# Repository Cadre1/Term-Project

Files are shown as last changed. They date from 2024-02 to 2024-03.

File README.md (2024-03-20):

# Term Project
 Group 18's Term Project
 
 Christopher Ng, Dylan Featherson, Edward Eyre

# Introduction
This project introduces an autonomous turret system designed to display enhanced target acquisition and firing capabilities for Nerf or similar projectile launchers. The primary purpose of this device is to autonomously locate the centroid of heat in a designated area through a thermal camera and adjust the yaw of the Nerf gun to aim precisely at the detected target. While the pitch remains fixed, our turret system ensures accurate horizontal alignment for firing at the identified heat source. The device is primarily intended for recreational use, targeting enthusiasts of Nerf or similar foam projectile launchers who seek an enhanced and automated shooting experience. Additionally, our turret system can be of interest to hobbyists, makers, and engineering students interested in exploring mechatronics, automation, and robotics applications. With its autonomous targeting capabilities, the device offers a unique and engaging way to enjoy Nerf battles while showcasing advancements in technology integration and automation.

# Final Product




The Project in Action - https://youtu.be/ceA77QBQG_Y?si=SO-bap_1HtrvdEz_

# Hardware Design
Using the CAD model shown here and parts provided in the CAD folder, we developed laser printed wood parts for the main structural design of the turret along with specific 3D printed parts for components such as electronic fixtures, gears, and other small parts with sizings measured for the actual products. 



# Electronic Schematic
Using the electronic schematic shown here, we wired the STM32 Nucleo to its corresponding electronic components with extended wires and external power sources.



# Software Design
Using the finite state machines shown here, we programmed our system accordingly to produce our controlled results. 

The program documentation can be found here - https://cadre1.github.io/Term-Project/




# Results
Our system underwent rigorous testing on the designated battle table, which spanned 8 feet in length. During these tests, we evaluated its performance in various scenarios by setting up targets at different positions, heat levels, and time settings. Provided enough testing for general settings, the system demonstrated accurate target acquisition and aiming, proving its reliability under simulated battle conditions. With proper calibration of the IR sensor and a functional Nerf gun, the turret successfully located and fired at targets with precision, showcasing its effectiveness in autonomous operation.

# Challenges and Lessons Learned
Despite its overall success, we encountered challenges primarily related to mechanical components, particularly the undersized 3D printed spur gear teeth, and some detection of hotspots. Issues with too shallow of gear teeth depth and wear due to material choice and sizing resulted in occasional slipping and improper meshing of gears, necessitating slow and careful adjustments to ensure smooth turret rotation. This mainly showed to our lack in experience in developing gears for situations under medium amounts of play between moving parts. Provided more time, this issue could have been remedied by recutting wood and moving the motor location to better contact the annular gear, increasing gear teeth sizes, and/or altering our gear type to be spur gears to be able to mesh the two and have more room for error. In addition, maintaining proper calibration of the IR sensor and addressing potential jams in the Nerf gun were critical for optimal performance. Further adjustments for higher mounting of the thermal camera or a more sophisticated algorithim for horizontal hotspot calculation could have helped in aiming. From these challenges, we learned the importance of meticulous component sizing and compatibility checks, as well as the significance of thorough calibration procedures for sensor-based systems.



# Recomendations
For those seeking to build upon our work, we recommend prioritizing careful sizing and compatibility checks of mechanical components to prevent issues such as gear slipping. Additionally, implementing regular maintenance checks and calibration procedures for sensors and actuators is essential for consistent performance. Exploring alternative materials or manufacturing methods for gears could improve durability and reliability. Furthermore, integrating additional sensors or advanced algorithms for target tracking could enhance the system's accuracy and adaptability in dynamic environments. Overall, these recommendations aim to address challenges encountered during our project and offer avenues for further refinement and improvement in future iterations.

# References
Inspiration for the project: 

Vinnie San’s automatic turret - https://www.youtube.com/watch?v=dkEc3wjEfYc

<br>

Hardware and software manuals and support documents:

Helpful Code for ME 405 - https://github.com/spluttflob/ME405-Support

STM32L476 Nucleo User Manual - https://www.st.com/resource/en/user_manual/um1724-stm32-nucleo64-boards-mb1136-stmicroelectronics.pdf

MLX90640 Thermal Camera Datasheet - https://www.melexis.com/en/documents/documentation/datasheets/datasheet-mlx90640

HEXFLY 25kg Metal Gear Servo Specifications - https://www.redcatracing.com/products/rer11856?variant=30993858625626

IRLB8721PbF MOSFET Datasheet - https://www.infineon.com/dgdl/irlb8721pbf.pdf?fileId=5546d462533600a40153566056732591

L7805CV Voltage Regulator Datasheet - https://www.mouser.com/datasheet/2/389/l78-1849632.pdf

Nerf Gun - https://www.amazon.com/NERF-Motorized-Blaster-6-Dart-Compatible/dp/B08HSRQ1QV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

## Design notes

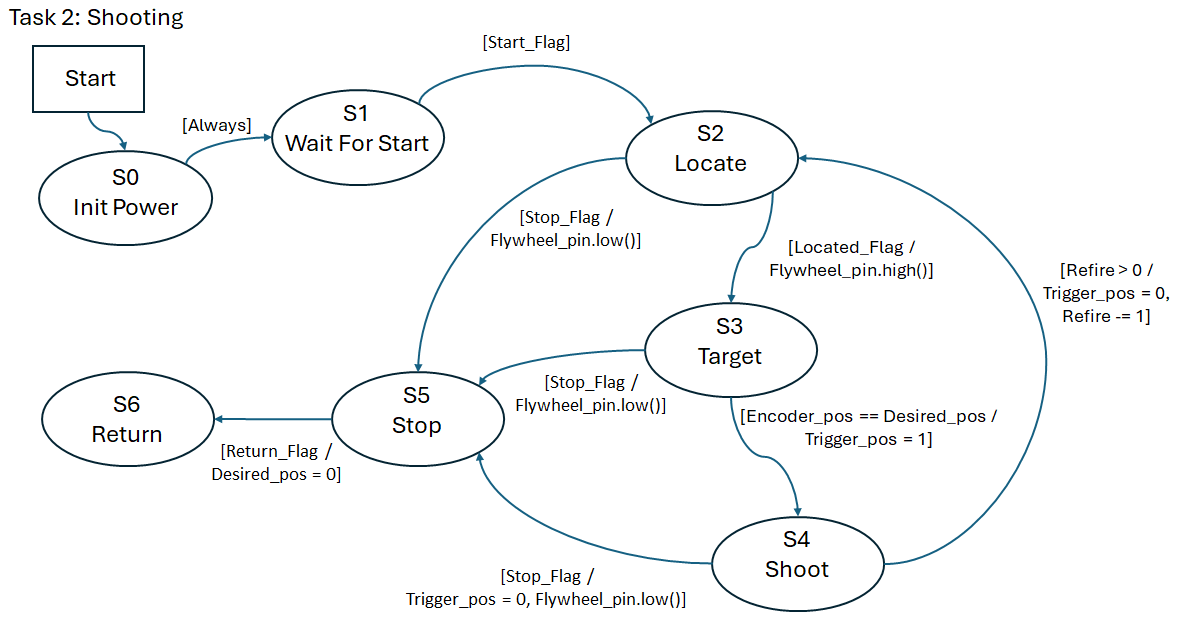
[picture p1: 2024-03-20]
docs/Task2_FSM.png

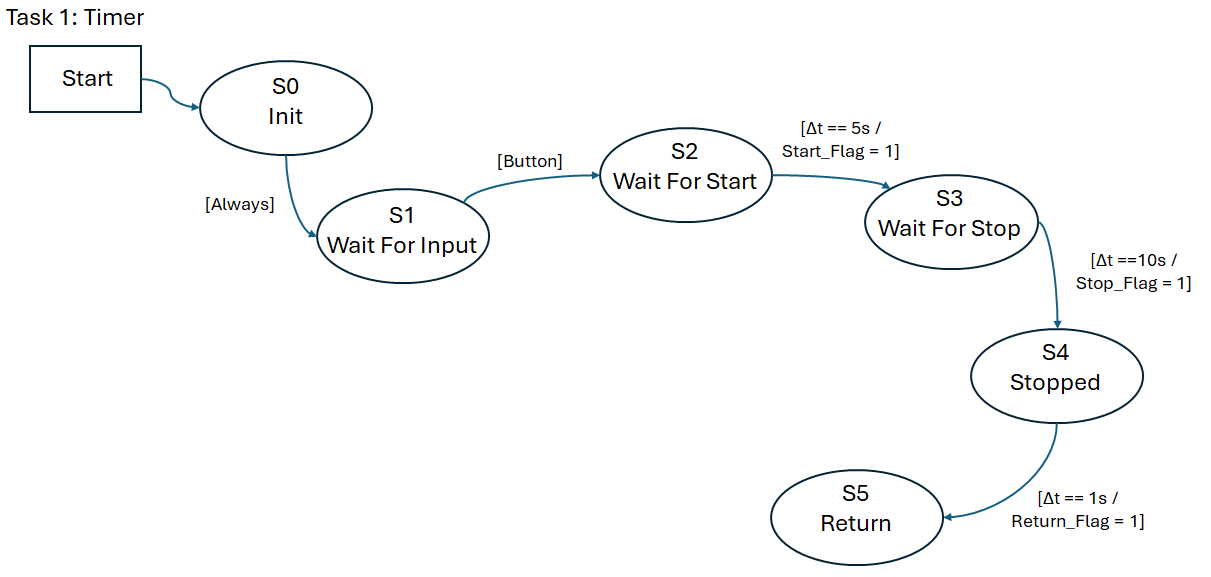
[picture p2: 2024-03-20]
docs/Task1_FSM.png

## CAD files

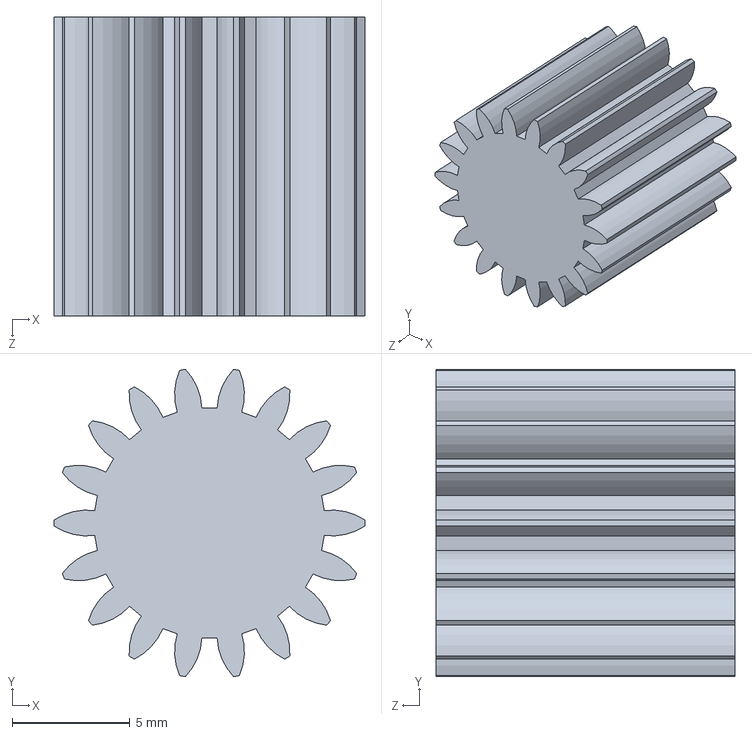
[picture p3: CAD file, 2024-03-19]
CAD/3D Print Parts/Pinion_Gear.SLDPRT
13.2 x 13.1 x 12.7 mm

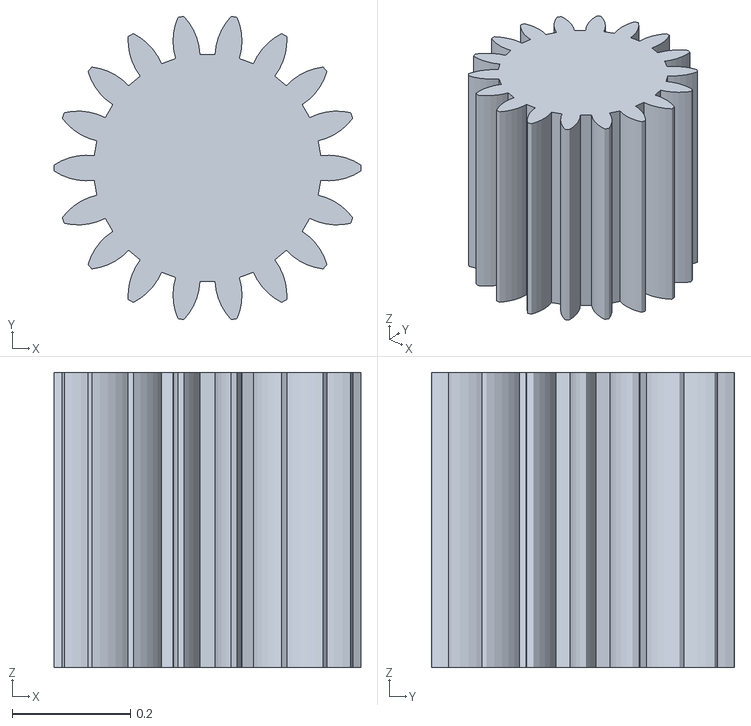
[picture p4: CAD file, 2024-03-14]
CAD/Pinion_GearV3_Large_Teeth.STL
0.52 x 0.514 x 0.5

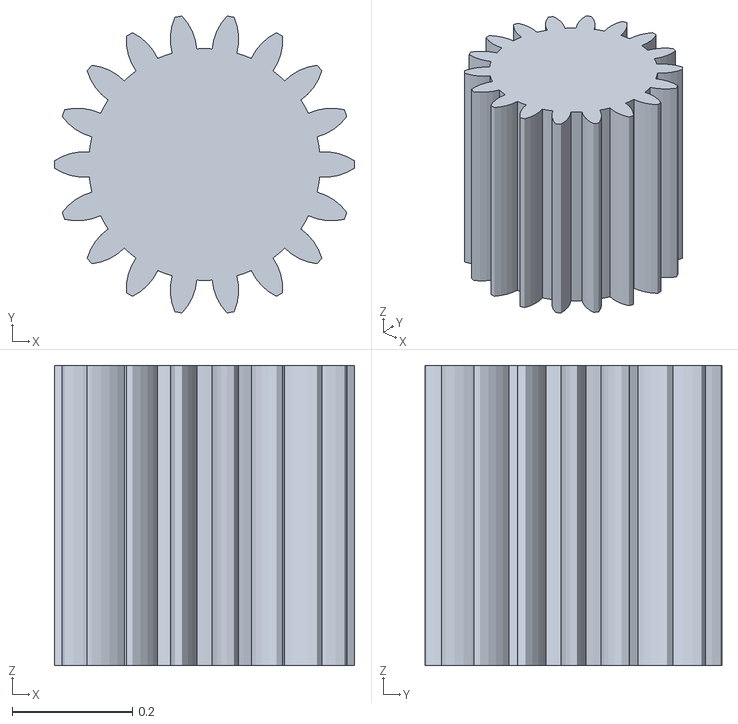
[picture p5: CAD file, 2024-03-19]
CAD/3D Print Parts/Pinion_GearV3.STL
0.5 x 0.494 x 0.5

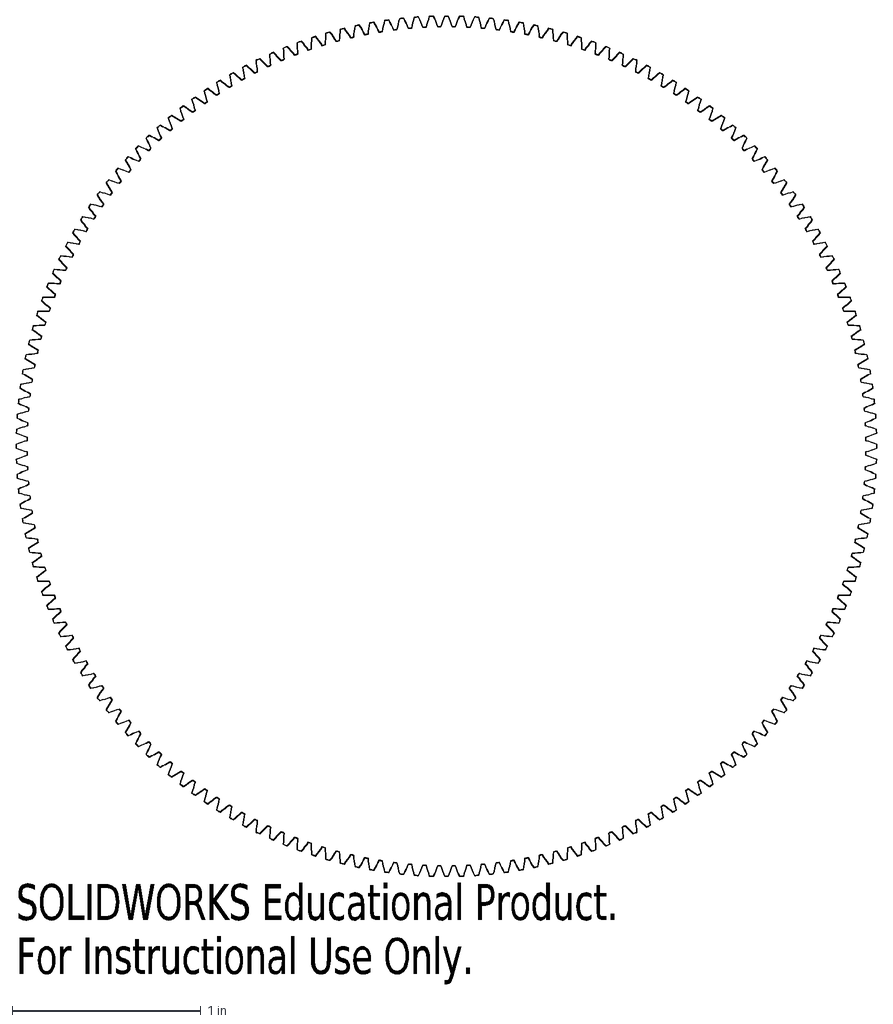
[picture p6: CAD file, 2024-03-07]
CAD/internal spur gear_ai_modified.DXF
SOLIDWORKS Educational Product.
For Instructional Use Only.

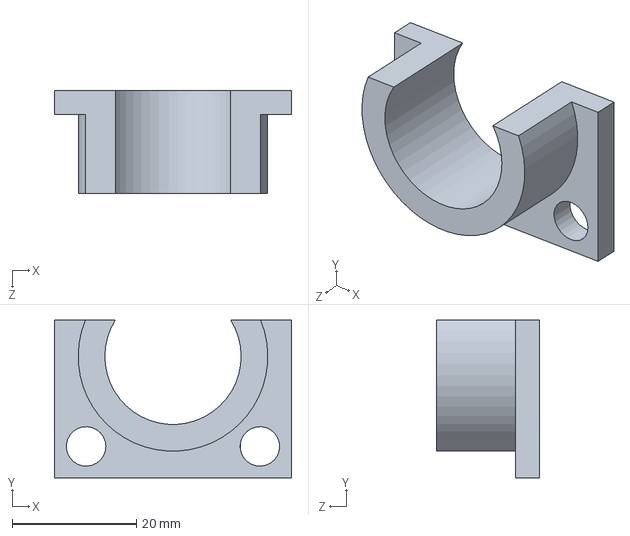
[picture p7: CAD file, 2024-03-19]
CAD/3D Print Parts/Vertical_Motor_Holder.SLDPRT
38.1 x 25.4 x 16.5 mm

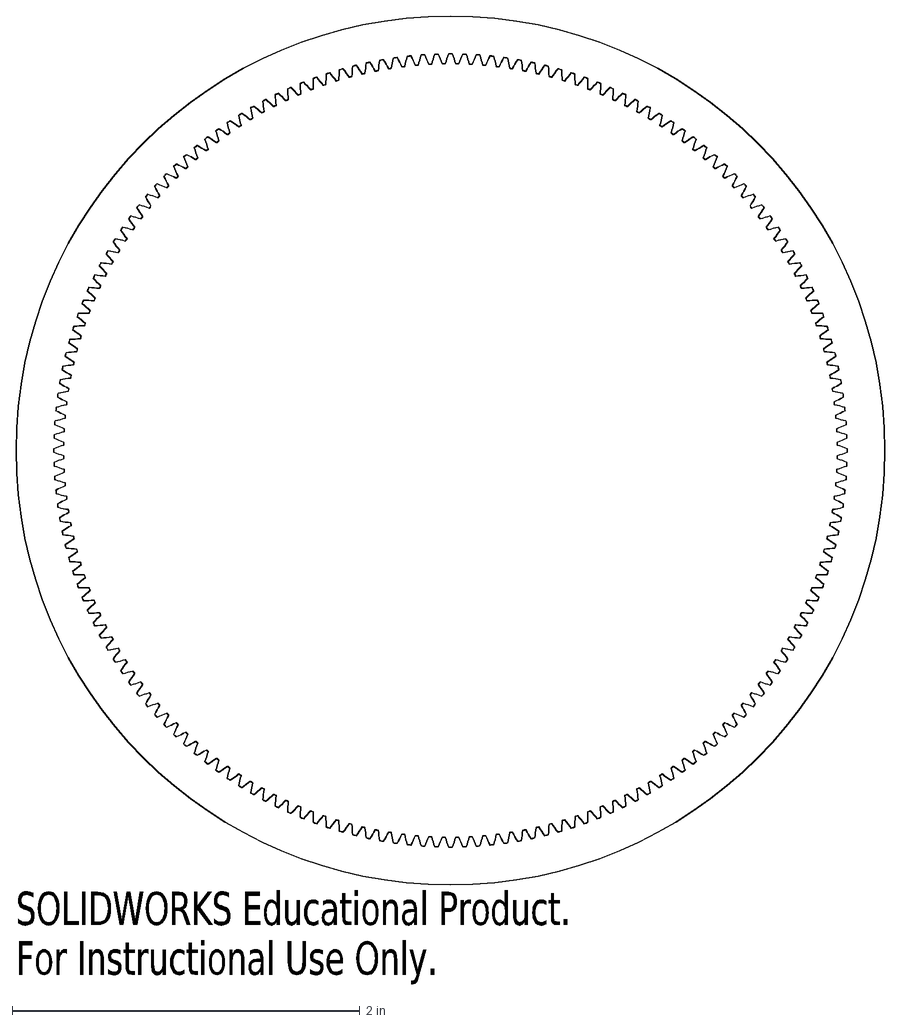
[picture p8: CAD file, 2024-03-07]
CAD/internal spur gear_ai.DXF
SOLIDWORKS Educational Product.
For Instructional Use Only.

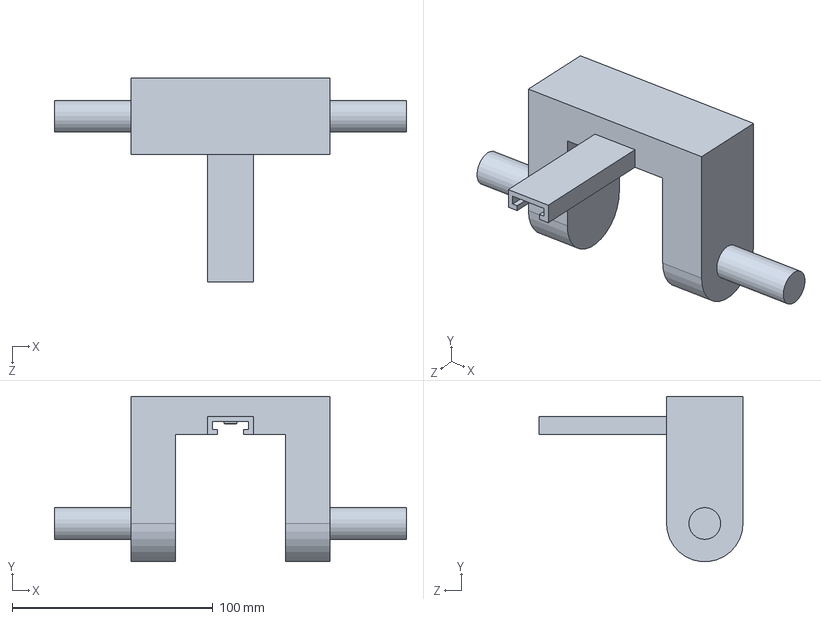
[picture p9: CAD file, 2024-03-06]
CAD/3D Print Parts/Nerf_Gun_Rail_Attachment.SLDPRT
175.3 x 82.2 x 101.6 mm

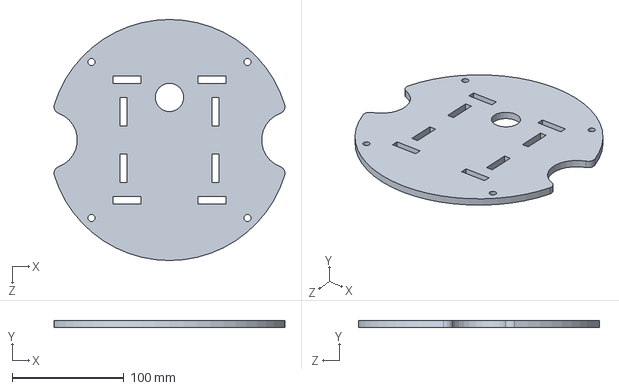
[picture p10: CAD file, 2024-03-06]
CAD/Base.SLDPRT
206.9 x 6.35 x 215.9 mm

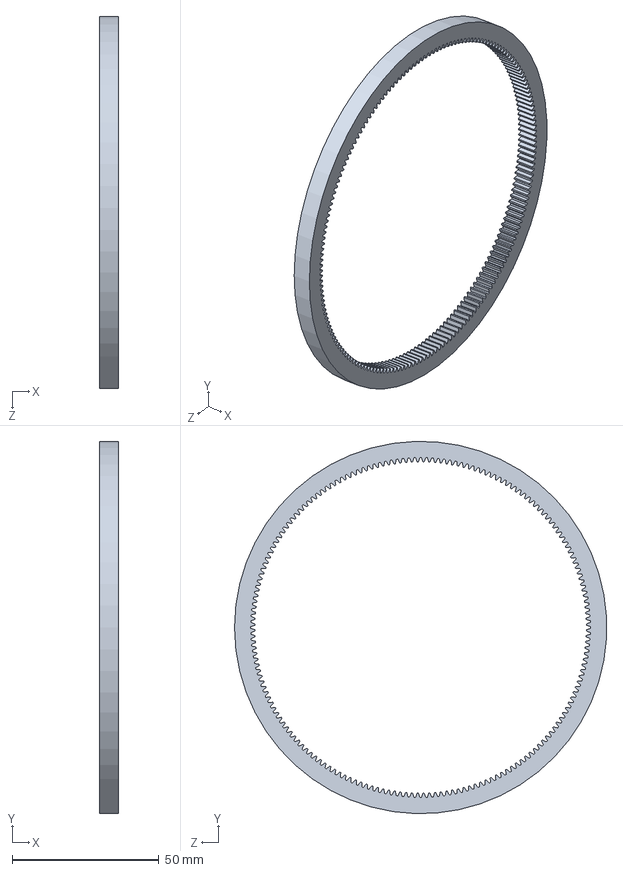
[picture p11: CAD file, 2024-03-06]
CAD/3D Print Parts/Annular_Gear.SLDPRT
6.35 x 126.9 x 126.9 mm

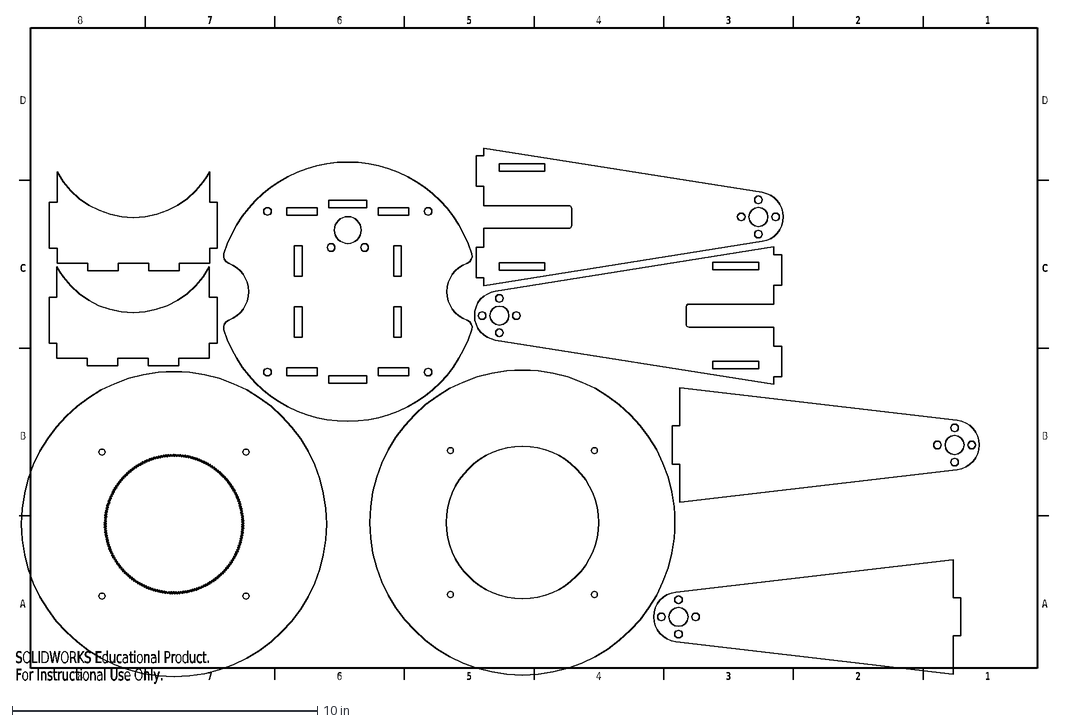
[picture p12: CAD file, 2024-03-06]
CAD/Laser_Cut.DXF
A
B
C
D
8
7
6
5
4
3
2
1
SOLIDWORKS Educational Product.
For Instructional Use Only.

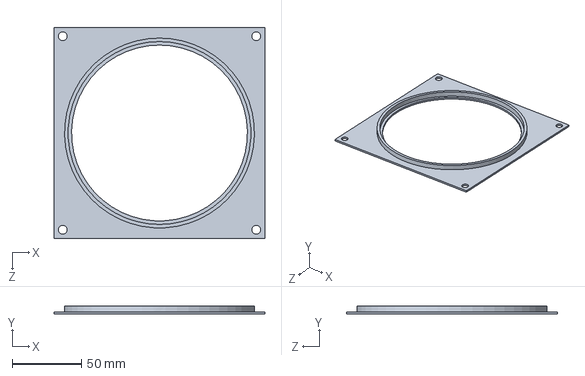
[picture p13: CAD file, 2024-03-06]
CAD/Lazy Susan Bottom Rotatable.SLDPRT
152.4 x 6.03 x 152.4 mm

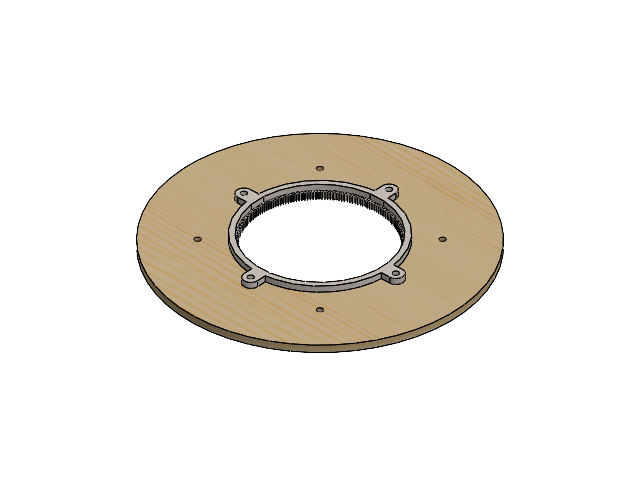
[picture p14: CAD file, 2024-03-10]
CAD/Base_Plate.SLDASM
internal spur gear_ai
Table Support Rotatable

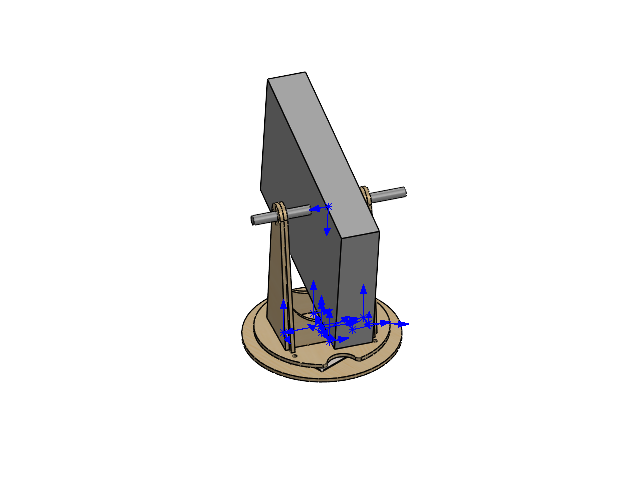
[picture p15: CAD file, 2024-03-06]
CAD/Assembly.SLDASM
Base
Supports x 2
Lazy Susan
Lazy Susan Bottom Rotatable
Truss x 2
Truss Support x 2
Nerf Gun and Axle
Motor Stand-In
internal spur gear_ai
Table Support Rotatable
Pinion_Gear
Vertical_Motor_Holder

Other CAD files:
CAD/3D Print Parts/Pinion_Gear_More_Fill.SLDPRT
CAD/Truss Support.SLDPRT
CAD/Motor Stand-In.SLDPRT
CAD/Supports.SLDPRT
CAD/Table Support Rotatable.SLDPRT
CAD/3D Print Parts/Annular_Gear.STL
CAD/3D Print Parts/Nerf_Gun_Rail_Attachment.STL
CAD/3D Print Parts/Pinion_Gear.STL
CAD/3D Print Parts/Pinion_GearV2.STL
CAD/3D Print Parts/Pinion_Gear_More_Fill.STL
CAD/3D Print Parts/Vertical_Motor_Holder.STL
CAD/Assembly.SLDDRW
CAD/Base Gear.SLDPRT
CAD/Base.DXF
CAD/Bearing Restraint.SLDPRT
CAD/Bearing Stand In.SLDPRT
CAD/Bottom Gear.SLDPRT
CAD/Laser_Cut.DWG
CAD/Laser_Cut.SLDDRW
CAD/Lazy Susan.SLDPRT
CAD/Motor Pulley.SLDPRT
CAD/Nerf Gun and Axle.SLDPRT
CAD/Pinion_GearV2_Large_Teeth.STL
CAD/Shaft Pulley.SLDPRT
CAD/Supports.DXF
CAD/Table Support Rotatable.DXF
CAD/Truss Support.DXF
CAD/Truss.DXF
CAD/Truss.SLDPRT

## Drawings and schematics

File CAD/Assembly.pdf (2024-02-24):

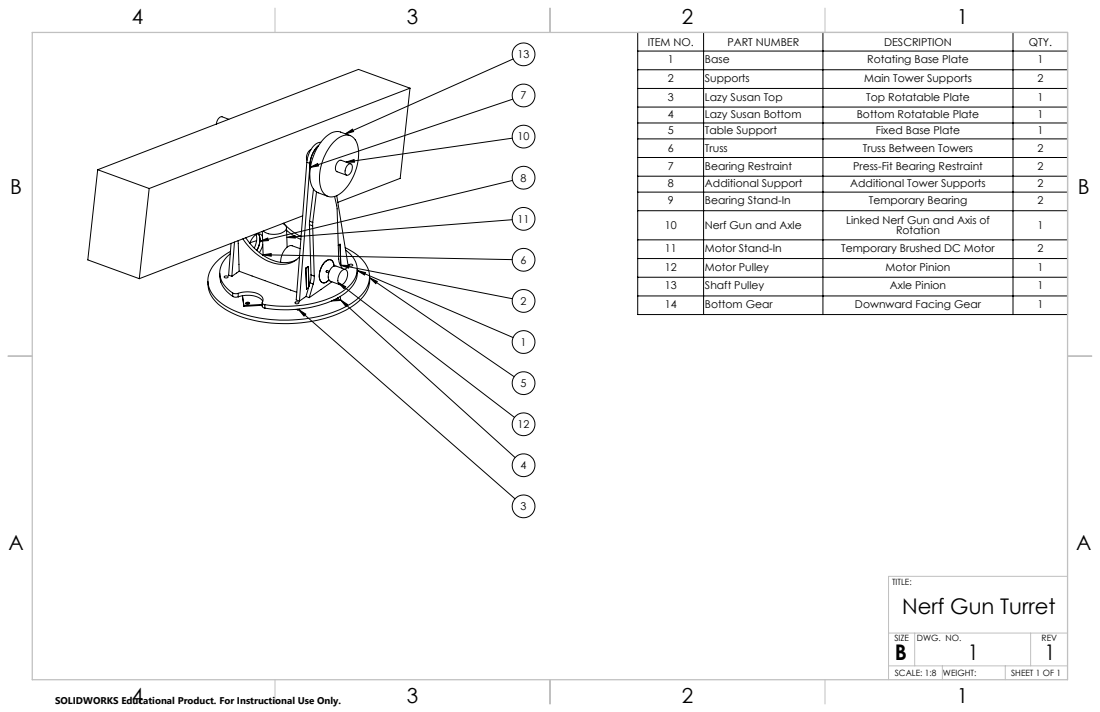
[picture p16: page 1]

ITEM NO. | PART NUMBER | DESCRIPTION | QTY.
1 | Base | Rotating Base Plate | 1
2 | Supports | Main Tower Supports | 2
3 | Lazy Susan Top | Top Rotatable Plate | 1
4 | Lazy Susan Bottom | Bottom Rotatable Plate | 1
5 | Table Support | Fixed Base Plate | 1
6 | Truss | Truss Between Towers | 2
7 | Bearing Restraint | Press-Fit Bearing Restraint | 2
8 | Additional Support | Additional Tower Supports | 2
9 | Bearing Stand-In | Temporary Bearing | 2
10 | Nerf Gun and Axle | Linked Nerf Gun and Axis of Rotation | 1
11 | Motor Stand-In | Temporary Brushed DC Motor | 2
12 | Motor Pulley | Motor Pinion | 1
13 | Shaft Pulley | Axle Pinion | 1
14 | Bottom Gear | Downward Facing Gear | 1

TITLE:
Nerf Gun Turret

SIZE B | DWG. NO. 1 | REV 1

SCALE: 1:8 | WEIGHT: | SHEET 1 OF 1

SOLIDWORKS Educational Product. For Instructional Use Only.

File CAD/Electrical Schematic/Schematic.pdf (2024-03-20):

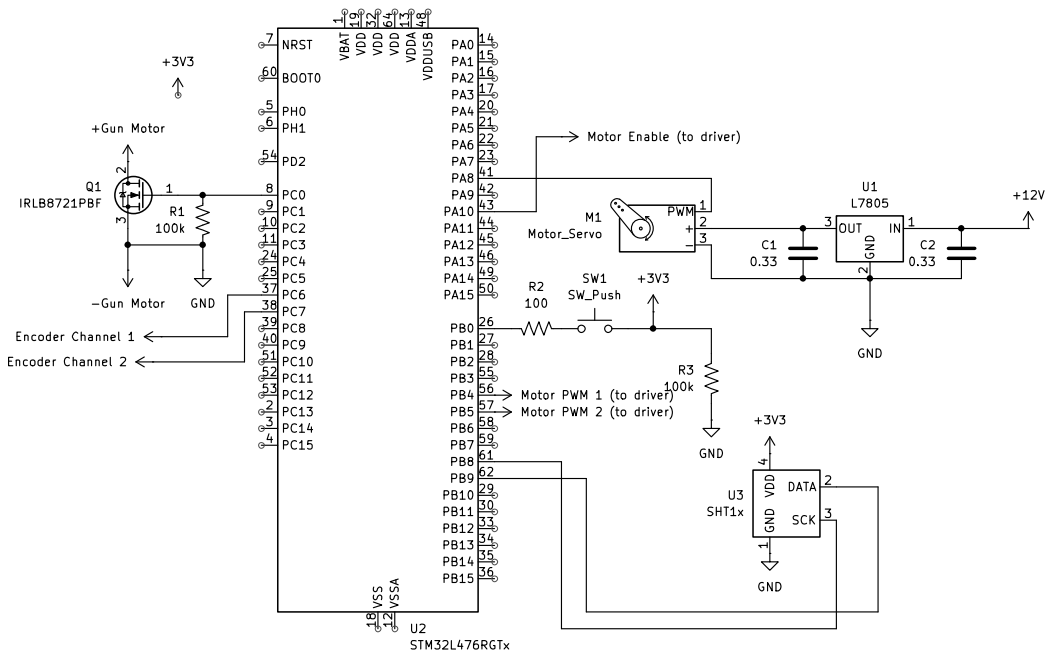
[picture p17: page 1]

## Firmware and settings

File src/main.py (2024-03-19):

"""!
@file main.py
    This program manages and allows two cotasks, task1_fun (Timing) and task2_fun (Shooting), to be run without blocking each other upon the microcontroller's reset.
    The Timing task initializes a pin to take an input from a button in which it then begins to track each of the required timers for the shootout.
    Each section of the shootout will have its corresponding flag set when each timer ends.
    The Shooting task initializes the pin controlling the MOSFET output to the Nerf gun flywheel, the I2C channel for the thermal camera, the pins and timers for the panning motor and encoder, and the pin, timer, and PID controller for the servo motor.
    This task will then manage the motor control for initial rotation using the motor driver, encoder, and PID controller, the centroid/hotspot detection using the thermal camera, the aiming at the determined centroid/hotspot, firing using the pin-to-flywheel circuit and servo motor, and rotation back to its starting point.
    During each of the shootout's sections, the states will be watching for changes in the timer's flag changes and change modes correspondingly. 
    Notes:
    * Each of these tasks' finite state machines can be found in the README on Github.
    * Tuning of controller gains, thermal readings, and timings may be adjusted per the requirements of operation by searching for "EDIT:" comments.
"""

import gc
import pyb
import utime
import cotask
import task_share
import motor_driver
import encoder_reader
import mlx_cam
import motor_control
import servo
from machine import Pin, I2C

      
def task1_fun(shares):
    """!
    Timing task that determines how long each section of the shootout will last
    @param shares A list holding the four shares, Start_Flag, Stop_Flag, Return_Flag, and Button_Flag set by this task
    """
    # Gets references to the shares which have been passed to this task
    Start_Flag, Stop_Flag, Return_Flag, Button_Flag = shares
    # Init yield
    yield 0
    
    # Timing task's state management
    state = 0
    while True:
        if state == 0:
            """!
            S0: Init
            Initializes the required pins and flags used in the Timing task
            """
            print('state 0 for task 1')
            # Initializes input pin for the starting button
            pinB0 = pyb.ADC(pyb.Pin.board.PB0)
            # Initializes intertask flag variables
            Start_Flag.put(0)
            Stop_Flag.put(0)
            Return_Flag.put(0)
            Button_Flag.put(0)
            state = 1
            print('state 1 for task 1')
        elif state == 1:
            """!
            S1: Wait For Input
            Waits for an input from the initialized GPIO pin wired to the starting button
            """
            # Checks if the starting button pin reads a voltage greater than 2V (should be around 3.3V minus voltage drops across wires and resistors)
            # Then changes state and sets the Button_Flag
            if (pinB0.read()*3.3/4095) >= 2:
                state = 2
                Button_Flag.put(1)
                print('state 2 for task 1')
        elif state == 2:
            """!
            S2: Wait For Start
            Waits 5 seconds for the starting phase, in which the target can move around, to end
            """
            # Sets up a 5 second timer to wait until it elapses
            # Then changes state and sets the Start_Flag
            time_interval = 5000 # 5 second overall run time
            start_time = utime.ticks_ms()
            end_time = utime.ticks_add(start_time,time_interval)
            curr_time = start_time
            while utime.ticks_diff(end_time,curr_time) > 0:
                curr_time = utime.ticks_ms()
                yield 0
            Start_Flag.put(1)
            state = 3
            print('state 3 for task 1')
        elif state == 3:
            """!
            S3: Wait For Stop
            Waits 10 seconds for the shooting phase, in which the turret is allowed to fire, to end
            """
            # Sets up a 10 second timer to wait until it elapses
            # Then changes state and sets the Stop_Flag
            time_interval = 10000 # 10 second overall run time
            start_time = utime.ticks_ms()
            end_time = utime.ticks_add(start_time,time_interval)
            curr_time = start_time
            while utime.ticks_diff(end_time,curr_time) > 0:
                curr_time = utime.ticks_ms()
                yield 0
            Start_Flag.put(0)
            Stop_Flag.put(1)
            state = 4
            print('state 4 for task 1')
        elif state == 4:
            """!
            S4: Stopped
            Waits 1 second for the for the turret to stop before returning to its original position
            """
            # Sets up a 1 second timer to wait until it elapses
            # Then changes state and sets the Return_Flag
            time_interval = 1000 # 1 second overall run time
            start_time = utime.ticks_ms()
            end_time = utime.ticks_add(start_time,time_interval)
            curr_time = start_time
            while utime.ticks_diff(end_time,curr_time) > 0:
                curr_time = utime.ticks_ms()
                yield 0
            Stop_Flag.put(0)
            Return_Flag.put(1)
            state = 5
            print('state 5 for task 1')
        elif state == 5:
            """!
            S5: Return
            Waits 3 seconds for the for the turret to return to its original position
            """
            # Sets up a 3 second timer to wait until it elapses
            time_interval = 3000 # 3 second overall run time
            start_time = utime.ticks_ms()
            end_time = utime.ticks_add(start_time,time_interval)
            curr_time = start_time
            while utime.ticks_diff(end_time,curr_time) > 0:
                curr_time = utime.ticks_ms()
                yield 0
            Return_Flag.put(0)
        yield 0
            
      
def task2_fun(shares):
    """!
    Shooting task that controls the targetting, panning, and firing of the Nerf gun turret with its timings to change certain states set by the Timer task
    @param shares A list holding the three shares, Start_Flag, Stop_Flag, Return_Flag, and Button_Flag used by this task
    """
    # Get references to the share and queue which have been passed to this task
    Start_Flag, Stop_Flag, Return_Flag, Button_Flag = shares
    # Init yield
    yield 0
    
    # Shooting task's state management
    state = 0
    while True:
        if state == 0:
            """!
            S0: Init
            Initializes the required pins, timers, I2C channels, drivers, controller variables, and miscellaneous setting variables for the panning motor, encoder, flywheel GPIO pin, thermal camera, and servo
            """
            print('state 0 for task 2')

            # Initializes the GPIO Pin for the flywheel motor MOSFET
            PC1 = pyb.Pin(pyb.Pin.board.PC1, pyb.Pin.OUT_PP)
            PC1.low()

            # Initializes the I2C for the thermal camera
            i2c_bus = I2C(1)
            # Selects MLX90640 camera I2C address, normally 0x33, and check the bus
            i2c_address = 0x33
            scanhex = [f"0x{addr:X}" for addr in i2c_bus.scan()]
            print(f"I2C Scan: {scanhex}")
            # Creates the camera object and set it up in default mode
            camera = mlx_cam.MLX_Cam(i2c_bus)
            print(f"Current refresh rate: {camera._camera.refresh_rate}")
            camera._camera.refresh_rate = 10.0
            print(f"Refresh rate is now:  {camera._camera.refresh_rate}")
    
            # Initializes the motor pins and timers
            a_pin = pyb.Pin(pyb.Pin.board.PA10, pyb.Pin.OUT_PP)
            in1pin = pyb.Pin(pyb.Pin.board.PB4, pyb.Pin.OUT_PP)
            in2pin = pyb.Pin(pyb.Pin.board.PB5, pyb.Pin.OUT_PP)
            a_timer = pyb.Timer(3, freq=1000)
            # Creates the motor driver object
            moe = motor_driver.MotorDriver(a_pin, in1pin, in2pin, a_timer)
            moe.enable()

            # Initializes the encoder counter and pins
            timer_C = pyb.Timer(8, period=65535, prescaler=0)
            pinC6 = pyb.Pin(pyb.Pin.board.PC6)
            pinC7 = pyb.Pin(pyb.Pin.board.PC7)
            # Creates the encoder object
            enc = encoder_reader.Encoder(pinC6, pinC7, timer_C)
            
            # PID controller setup
            # Initializes controller gains and setpoint
            des_pos = 0
            Kp = 0
            Ki = 0
            Kd = 0
            setpoint = 0
            # Creates the motor controller object
            moe_con = motor_control.MotorControl(setpoint, Kp, Ki, Kd)
            
            # Initializes the servo pins and timers
            servo_pin = pyb.Pin(pyb.Pin.board.PA8, pyb.Pin.OUT_PP)
            s_timer = pyb.Timer(1, prescaler=79, period=19999)
            my_servo = servo.Servo(pin=servo_pin, timer=s_timer, zero_angle=80)
            
            # Miscellaneous setting variables
            shoot = 1
            refire = 0 # EDIT: Adjust for the number of ADDITIONAL shots
            state = 1
            print('state 1 for task 2')
        elif state == 1:
            """!
            S3: Wait For Start
            Rotates the turret 180 degrees and waits during the initial 5 seconds until the Timer task sets the Start_Flag
            """
            # Waits for the start of the shooting phase
            if Start_Flag.get():
                state = 2
                print('state 2 for task 2')
            
            # Rotates the turret 180 degrees (count of 80000)
            elif Button_Flag.get():  
                # Sets the setpoint corresponding to 180 degrees and sets the gains for the controller
                des_pos = 80000
                setpoint = des_pos
                Kp = 0.25
                Ki = 0
                Kd = 0
                moe_con.set_gain(Kp, Ki, Kd)
                moe_con.set_setpoint(setpoint)
                    
                # Runs the PID controlled motor until the encoder reads that the motor position is within a stay-within-range, range_interval, for a stay-within-range time, time_interval
                time_interval = 1000 # 1 second stay-within-range time
                range_interval = 1000 # 1000 count stay-within-range
                first_time = 1 # Check for initial stay-within-range
                while True:
                    if Start_Flag.get():
                        state = 2
                        print('state 2 for task 2')
                        break
                    else:
                        curr_time = utime.ticks_ms()
                        pos = enc.read_position()
                        PWM = moe_con.run(pos, 7)
                        moe.set_duty_cycle(PWM)
                        # Checks if we are within the stay-within-range interval of our desired position and starts the stay-within-range timer
                        if pos >= (des_pos-range_interval) and pos <= (des_pos+range_interval):
                            if first_time:
                                start_time = utime.ticks_ms()
                                end_time = utime.ticks_add(start_time,time_interval)
                                curr_time = start_time
                                first_time = 0
                            elif utime.ticks_diff(end_time,curr_time) < 0:
                                first_time = 1
                                moe.set_duty_cycle(0)
                                Button_Flag.put(0)
                                break
                        else:
                            first_time = 1
                    yield 0
        elif state == 2:
            """!
            S2: Locate
            Uses the thermal camera to determine the centroid/hotspot where the target should be locatedand calculates the required position the motor needs to move to
            """
            # Determines the position that the turret needs to be at to be centered on the target
            if Stop_Flag.get():
                state = 5
                print('state 5 for task 2')
            else:
                Button_Flag.put(0)
                # Turns on the flywheel
                PC1.high()
                # Keeps trying to get an image until it collects one
                image = None
                while not image:
                    if Stop_Flag.get():
                        state = 5
                        print('state 5 for task 2')
                        break
                    image = camera.get_image_nonblocking()
                    yield 0
                
                # Processes image to get the centroid and hotspot of the hottest region, ignoring temperatures besides those between the ignore range (%)
                ignore = [91, 100] # EDIT: Adjust until we get an appropriate/accurate shot (See camera outputs in mlx_cam.py if needed)
                centered = True # Boolean for x-y locations either from the top-left corner or from the center
                x_bar_centroid, y_bar_centroid = camera.get_centroid(image, ignore, centered)
                x_bar_hotspot, y_bar_hotspot = camera.get_hotspot(image, centered)
                
                # Calculates the angle of the weighted average of the centroid and hotspot X-positions for the 32x28 pixel resolution camera
                count_per_180 = 80000 # Counts per 180 degrees
                count_per_degree = count_per_180/180 # Count per every 1 degree
                weight_dist = [70/100, 30/100] # EDIT: Adjust to make the effect of centroid or hotspot more impactful
                horz_angle_centroid = 55/32*x_bar_centroid
                horz_angle_hotspot = 55/32*x_bar_hotspot
                horz_angle = (horz_angle_centroid*weight_dist[0]+horz_angle_hotspot*weight_dist[1])/2
                print(f'Centroid X: {horz_angle_centroid}')
                print(f'Hotspot X: {horz_angle_hotspot}')
                print(f'Weighted Average X: {horz_angle}')
                
                # Calculates the count position of the motor
                dcount = horz_angle*count_per_degree
                des_pos = count_per_180 + dcount
                state = 3
                print('state 3 for task 2')
        elif state == 3:
            """!
            S3: Target
            Uses the motor position calculated from the Locate state to rotate the turret correspondingly
            """
            # Rerotates the turret to the new located position
            if Stop_Flag.get():
                state = 5
                print('state 5 for task 2')
            else:
                # Turns on the flywheel
                PC1.high()
                # Sets the setpoint corresponding to the calculated position and sets the gains for the controller
                setpoint = des_pos
                Kp = 0.2 # EDIT: Adjust Kp if there is a lot of slip(?)
                Ki = 0 # EDIT: You shouldn't need to touch Ki or Kd. Time-to-speed isn't that bad and gear slip is worse.
                Kd = 0
                moe_con.set_gain(Kp, Ki, Kd)
                moe_con.set_setpoint(setpoint)
                
                # EDIT: Adjust time_interval and range_interval if you need shorter waiting time before firing and don't care as much about accuracy
                # (decrease time_interval, increase range_interval)
                time_interval = 100 # 0.1 second stay-within-range time
                range_interval = 2000 # 2000 count stay-within-range
                first_time = 1
                # Runs the PID controlled motor until the encoder reads that the motor position is within a stay-within-range, range_interval, for a stay-within-range time, time_interval
                while True:
                    if Stop_Flag.get():
                        state = 5
                        print('state 5 for task 2')
                        break
                    else:
                        curr_time = utime.ticks_ms()
                        pos = enc.read_position()
                        PWM = moe_con.run(pos, 7)
                        moe.set_duty_cycle(PWM)
                        # Checks if we are within the stay-within-range interval of our desired position and starts the stay-within-range timer
                        if pos >= (des_pos-range_interval) and pos <= (des_pos+range_interval):
                            if first_time:
                                start_time = utime.ticks_ms()
                                end_time = utime.ticks_add(start_time,time_interval)
                                curr_time = start_time
                                first_time = 0
                            elif utime.ticks_diff(end_time,curr_time) < 0:
                                first_time = 1
                                moe.set_duty_cycle(0)
                                state = 4
                                print('state 4 for task 2')
                                break
                        else:
                            first_time = 1
                    yield 0
        elif state == 4:
            """!
            S4: Shoot
            Uses the flywheel and servo to pull the trigger and fire the Nerf dart at the motors set position
            """
            # Sets the servo position to either 45 for shooting or 80 for not shooting
            if Stop_Flag.get():
                state = 5
                print('state 5 for task 2')
            else:
                if shoot:
                    # Moves servo to firing angle of 45 degrees
                    my_servo.SetAngle(45)
                    refire -= 1
                    time_interval = 200 # 0.2 second overall run time
                    start_time = utime.ticks_ms()
                    end_time = utime.ticks_add(start_time,time_interval)
                    curr_time = start_time
                    while utime.ticks_diff(end_time,curr_time) > 0:
                        if Stop_Flag.get():
                            state = 5
                            break
                        curr_time = utime.ticks_ms()
                        yield 0
                    shoot = 0
                else:
                    # Moves servo to non-firing angle of 80 degrees and turns the flywheel off
                    my_servo.SetAngle(80)
                    PC1.low()
                    # Resets the shooting state and reloactes the target if refire isn't less than 0
                    if refire >= 0:
                        shoot = 1
                        state = 2
        elif state == 5:
            """!
            S5: Stop
            Stops all motor motion and resets the servo
            """
            # Sets pins and motors to passive settings
            PC1.low()
            moe.set_duty_cycle(0)
            my_servo.SetAngle(80)
            # Waits until the 10 seconds for firing has elapsed before returning
            if Return_Flag.get():
                des_pos = 0
                state = 6
                print('state 6 for task 2')
        elif state == 6:
            """!
            S6: Return
            Rotates the turret back to 0 degrees and disables the motors and waits
            """
            # Sets the setpoint to 0 degrees and sets the gains for the controller
            setpoint = des_pos
            Kp = 0.25
            Ki = 0
            Kd = 0
            moe_con.set_gain(Kp, Ki, Kd)
            moe_con.set_setpoint(setpoint)
                
            time_interval = 1000 # 1 second stay-within-range time
            range_interval = 2500 # 2500 count stay-within-range
            first_time = 1
            
            # Runs the PID controlled motor until the encoder reads that the motor position is within a stay-within-range, range_interval, for a stay-within-range time, time_interval
            while True:
                pos = enc.read_position()
                PWM = moe_con.run(pos, 7)
                moe.set_duty_cycle(PWM)
                # Checks if we are within the stay-within-range interval of our desired position and starts the stay-within-range timer
                if pos >= (des_pos-range_interval) and pos <= (des_pos+range_interval):
                    if first_time:
                        start_time = utime.ticks_ms()
                        end_time = utime.ticks_add(start_time,time_interval)
                        curr_time = start_time
                        first_time = 0
                    elif utime.ticks_diff(end_time,curr_time) > 0:
                        first_time = 1
                        moe.set_duty_cycle(0)
                        state = 4
                        break
                else:
                    first_time = 1
            
            # Turns off the motor and waits
            moe.set_duty_cycle(0)
            moe.disable()
            while True:
                yield 0
        yield 0
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

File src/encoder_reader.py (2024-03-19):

"""! @file encoder_reader.py
This program creates the class "Encoder" which initializes the timers/counters required for the encoder using provided channel pins and a timer/counter.
This class also contains the ability to set the read the overall motor position in radians or counts (being able to bypass overflow and underflow), and is able to zero at any position.
"""
import motor_driver
import utime
import pyb
import math

class Encoder:
    """! 
    This class sets up the encoder contained in a DC motor. 
    """
    def __init__(self, in6pin, in7pin, timer, CPR=256):
        """! 
        Creates an encoder by initializing timers as counters given their respective pins 
        @param in6pin The set up X6 encoder pin  
        @param in7pin The set up X7 encoder pin
        @param timer The set up counter with AR = period
        @param CPR The counts per revolution of the motor (assumed 256CPR)
        """
        self.prev_count = 0
        self.tot_count = 0
        self.CPR = CPR 
        
        try:
            # Initialized Counter  
            self.timer = timer
            # Initializing the Timer Channels
            self.timer_Encoder_6 = self.timer.channel(1,
                                                      pyb.Timer.ENC_AB,
                                                      pin=in6pin)
            self.timer_Encoder_7 = self.timer.channel(2,
                                                      pyb.Timer.ENC_AB,
                                                      pin=in7pin)
            print ("Created a encoder")
        except Exception as e:
            print(e)


    def read_position(self):
        """!
        This method calculates the current motor position
        and prints out the result. This motor position bypasses
        overflow and underflow, meaning it can count below and above
        the given timer period.
        @returns The total count position of the motor 
        """
        count = self.timer.counter()
        
        delta = count-self.prev_count
        AR = int(self.timer.period())
        
        # For overflow
        if delta <= -(AR+1)/2:
            self.tot_count += (AR+1)+delta
        # For underflow
        elif delta >= (AR+1)/2:
            self.tot_count += delta-(AR+1)
        else:
            self.tot_count += delta
        self.prev_count = count
        return self.tot_count
    
    
    def convert_count_to_rad(self):
        """!
        This method converts the total count from counts per revolution to radians
        @returns The total position of the motor in radians
        """
        tot_count_rad = self.tot_count*(2*(math.pi)/(self.CPR*4))
        return tot_count_rad
    
    
    def read_position_rad(self):
        """!
        This method returns the current motor position in radians
        @returns The total position of the motor in radians
        """
        self.read_position()
        return self.convert_count_to_rad()
    
        
    def zero(self):
        """!
        This method zeros the encoder at the current motor position.
        """
        self.tot_count = 0
        print(self.tot_count)
  
           
# Test Code
if __name__ == "__main__":
    # Initializing the Encoder Counters
    timer_B = pyb.Timer(4, period=65535, prescaler=0)
    timer_C = pyb.Timer(8, period=65535, prescaler=0)

    # Initializing the PWM Timers
    pinB6 = pyb.Pin(pyb.Pin.board.PB6)
    pinB7 = pyb.Pin(pyb.Pin.board.PB7)
    
    pinC6 = pyb.Pin(pyb.Pin.board.PC6)
    pinC7 = pyb.Pin(pyb.Pin.board.PC7)
    
    encoder_B = Encoder(pinB6, pinB7, timer_B)
    encoder_C = Encoder(pinC6, pinC7, timer_C)
    
    encoder_B.read_position_rad()
    
    # Hand Test
    while True:
        try:
            print(encoder_B.read_position())
            print(encoder_C.read_position())
            utime.sleep_ms(100)
        except KeyboardInterrupt:
            encoder_B.zero()
            encoder_C.zero()
            break

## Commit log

2024-02-01 Base Completed
    Turning base with holes cut for truss and braces.
    [Base.SLDPRT]
2024-02-01 Moving into a CAD folder
    [Base.SLDPRT]
2024-02-01 Moved Truss into shared file
    [Truss.SLDPRT]
2024-02-01 Preliminary CAD
    Have yet to add gears and other shit
    [Assembly.SLDASM, Base.SLDPRT, Lazy Susan Bottom Rotatable.SLDPRT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]
2024-02-01 Preliminary CAD
    0.25 inch wood, 0.75 inch shaft, 1.5 inch motor.
    [Assembly.SLDASM, Base.SLDPRT, Bearing Restraint.SLDPRT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]
2024-02-03 Final Preliminary CAD
    Added pulley and motor stand ins.
    [Assembly.SLDASM, Bottom Gear.SLDPRT, Motor Pulley.SLDPRT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]
2024-02-03 Basic Assembly Drawing
    [Assembly.SLDDRW]
2024-02-24 Some basic tweaks to find moment of inertia
    [Assembly.SLDASM, Nerf Gun and Axle.SLDPRT]
2024-03-03 Created the Initial Gear
    Hopefully this works, I used the gear toolbox for this, and hopefully it saved in the right place
    [Assembly.SLDASM, Base Gear.SLDPRT, Base.SLDPRT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]
2024-03-06 Final Simplification Changes
    Refined truss supports to eliminate uneccessary features
    [Assembly.SLDASM, Base.SLDPRT, Bearing Restraint.SLDPRT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]
2024-03-06 Final Final Wood CAD
    Fixed a rebuild error
    [Assembly.SLDASM, Base.SLDPRT, Nerf Gun and Axle.SLDPRT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]
2024-03-06 3D Printed Parts and Some updated Goemetry
    [Annular_Gear.SLDPRT, Assembly.SLDASM, Base.SLDPRT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]
2024-03-06 Updated CAD for Lazy Susan
    [Assembly.SLDASM, Base.SLDPRT, Base_Plate.SLDASM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]
2024-03-06 Laser Cut Sheet files
    [Assembly.SLDASM, Assembly.SLDDRW, Base.SLDPRT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]
2024-03-07 DXF files
    [Base.DXF, Supports.DXF, Table Support Rotatable.DXF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]
2024-03-10 Bunch of stuff
    [Annular_Gear.SLDPRT, Annular_Gear.STL, Base_Plate.SLDASM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]
2024-03-11 Servo Code
    still doesn't work
    [servo_main.py]
2024-03-11 Functioning Main
    Requires servo motor code
2024-03-13 Functioning Servo Driver!
2024-03-14 Tested/Tuned Programs
    [Pinion_GearV2_Large_Teeth.STL, Pinion_GearV3_Large_Teeth.STL]
2024-03-19 3D printed Parts
    [Annular_Gear.SLDPRT, Nerf_Gun_Rail_Attachment.SLDPRT, Pinion_Gear.SLDPRT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]
2024-03-19 Added Schematic
